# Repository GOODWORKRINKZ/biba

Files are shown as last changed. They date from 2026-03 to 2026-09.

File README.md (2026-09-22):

# BiBa




<p align="center">
   BiBa gradient ASCII logo
</p>

BiBa — это колесная робот-платформа с управлением по ExpressLRS/CRSF, телеметрией от Daly 6S BMS по BLE или USB-UART, двухканальными драйверами BTS7960 и звуковой индикацией через моторы. Платформа поддерживает три композиции железа — от чисто-Pi-варианта до связки одноплатник + STM32F103, поэтому репозиторий организован как hub: общие компоненты живут рядом, а сборки разводятся по подкаталогам.

## Архитектура

BiBa поддерживает три композиции железа. Где есть STM32 — именно он принимает CRSF и держит failsafe; одноплатник, если присутствует, работает как high-level brain поверх SPI-канала к STM32.

| Композиция | SBC (Raspberry Pi) | MCU add-on | Кто слушает CRSF | Compose / прошивка |
| --- | --- | --- | --- | --- |
| **A. Pi-only** (текущий продакшен) | да | нет | Pi (`/dev/ttyS0`) | [`docker/legacy-pi/docker-compose.yml`](docker/legacy-pi/docker-compose.yml) |
| **B. STM32-only** | нет | STM32F103 | STM32 | env `standalone` в [`firmware/`](firmware/) |
| **C. Pi + STM32** | да | STM32F103 | STM32 (Pi видит каналы через SPI-телеметрию) | env `companion` в [`firmware/`](firmware/) + ROS2-стек в `docker/ros2/` (в разработке) |
| **D. RP2040-only** (в разработке, ветка `rp2040-port`) | нет | RP2040 | RP2040 | env `rp2040_dc_bts7960_pwm_standalone` в [`firmware/`](firmware/) |

Канонический разбор композиций, их обязанности и failsafe-уровни — в [docs/system_architecture.md](docs/system_architecture.md). STM32-сторона детально описана в [docs/stm32_architecture.md](docs/stm32_architecture.md), будущий ROS2-стек композиции C — в [docs/ros2_stack.md](docs/ros2_stack.md). Общий design-doc и план редизайна — [docs/plans/2026-04-28-sbc-architecture-redesign-design.md](docs/plans/2026-04-28-sbc-architecture-redesign-design.md).

## Состав железа

- Raspberry Pi Zero 2W
- ELRS-приемник с подключением по UART/CRSF
- Daly BMS по BLE или с USB-UART адаптером
- 6S аккумулятор с телеметрией BMS
- Два драйвера BTS7960 для левого и правого моторов
- ADS1115 для current sense и телеметрии токов колёс (опционально)

## Распиновка

| Назначение | BCM | Физический пин |
| --- | --- | --- |
| ELRS TX | 14 | 8 |
| ELRS RX | 15 | 10 |
| I2C SDA (ADS1115, опционально) | 2 | 3 |
| I2C SCL (ADS1115, опционально) | 3 | 5 |
| Left BTS7960 RPWM | 12 | 32 |
| Left BTS7960 LPWM | 18 | 12 |
| Left BTS7960 REN | 23 | 16 |
| Left BTS7960 LEN | 24 | 18 |
| Right BTS7960 RPWM | 19 | 35 |
| Right BTS7960 LPWM | 13 | 33 |
| Right BTS7960 REN | 20 | 38 |
| Right BTS7960 LEN | 21 | 40 |
| GND драйвера | - | 14 |

Распиновка и таблица выше актуальны для композиции A (Pi-only). Для композиций B/C wiring между Pi, STM32 и силовой частью описан в [docs/wiring.md](docs/wiring.md) и [docs/stm32_architecture.md](docs/stm32_architecture.md).

Подробное описание подключения находится в [docs/wiring.md](docs/wiring.md).

Опциональная прошивка для STM32F103 ("Blue Pill") add-on, который умеет работать либо самостоятельно, либо SPI-slave-ом к Pi, живёт в [`firmware/`](firmware/). Архитектура описана в [docs/stm32_architecture.md](docs/stm32_architecture.md).

Текущий двухмоторный runtime на Pi Zero 2W должен быть запущен с `BTS7960_PWM_MODE=SOFTWARE`, потому что распиновка `12/18` и `19/13` делит общие hardware-PWM каналы. Это уже совпадает и с кодовым default в `config.py`, и с compose-default для развёрнутого робота.

## Структура репозитория

- `biba-controller/` — Python-контроллер для CRSF, моторов, моторного audio/voice runtime и телеметрии BMS (композиции A и C)
- `biba-controller/stm32_link/` — опциональный SPI-клиент к STM32F103 add-on (`STM32_LINK_ENABLED=1`, композиция C)
- `firmware/` — PlatformIO-проект прошивки (STM32F103C8T6 и RP2040): env'ы `standalone` для композиции B, `companion` для композиции C, `rp2040_dc_bts7960_pwm_standalone` для композиции D (ветка `rp2040-port`), `native_test` для host-side Unity-тестов
- `docker/` — каталог compose-стеков, разнесённых по композициям:
  - `docker/legacy-pi/` — текущий продакшен-стек композиции A
  - `docker/ros2/` — будущий ROS2-стек композиции C (в разработке)
  - `docker/base/` — общие базовые образы (в разработке)
- `lua/SCRIPTS/TELEMETRY/biba.lua` — экран телеметрии EdgeTX для оператора
- `.github/workflows/` — global builder workflows для Ruff, pytest, shellcheck и сборки arm64 Docker-образа в GHCR
- `scripts/setup/` — bringup-скрипты для Raspberry Pi (Docker, Compose, systemd-автозапуск)
- `scripts/biba_aliases.sh` — robot-side operational aliases, включая `bbupdate` для штатного обновления
- `scripts/diagnostics.sh` — диагностика хоста и контейнера
- `scripts/voice_prep.py` — офлайн-подготовка русскоязычных voice assets и явный promote в production voice каталог
- `voice-src/phrases.yml` — канонический набор русских фраз по событиям
- `voice-work/` — staging-каталог для сгенерированных кандидатов перед promote в production voice каталог
- `docs/deployment.md` — руководство по развёртыванию по композициям
- `docs/system_architecture.md` — канонический обзор всех трёх композиций
- `.agents/skills/` — вендорный каталог skills

## Quick-start по композициям

- **Композиция A (Pi-only).** Сегодняшний bringup-скрипт и compose-стек. Полный гайд: [docs/deployment.md](docs/deployment.md#композиция-a-pi-only).
- **Композиция B (STM32-only).** Без одноплатника. Сборка и заливка прошивки описаны в [firmware/README.md](firmware/README.md) и [docs/stm32_architecture.md](docs/stm32_architecture.md).
- **Композиция C (Pi + STM32).** В разработке. Проектная картина — в [design-doc](docs/plans/2026-04-28-sbc-architecture-redesign-design.md) и [docs/ros2_stack.md](docs/ros2_stack.md).

Дальше по тексту разделы про подготовку Pi, env-переменные, settings UI и motor trim относятся к композиции A.

## Подготовка Raspberry Pi (композиция A)

1. Включите UART на Raspberry Pi.
2. Освободите основной UART от Bluetooth, добавив в конфигурацию:

   ```ini
   enable_uart=1
   dtoverlay=disable-bt
   ```

3. Перезагрузите Raspberry Pi.
4. Настройте Daly BMS по BLE или подключите USB-UART адаптер, если используете UART-вариант.
5. Если используете ADS1115 для current sense, включите I2C и проверьте наличие `/dev/i2c-1`.

Вместо ручной установки Docker/Compose можно использовать bringup-скрипт:

```bash
curl -fsSL https://raw.githubusercontent.com/GOODWORKRINKZ/biba/main/scripts/setup/setup_node.sh | bash
```

Скрипт:

- ставит Docker и Docker Compose plugin
- ставит базовые системные утилиты
- клонирует или обновляет репозиторий в `~/biba`
- настраивает алиасы для управления стеком
- создает `systemd` unit для автозапуска `docker compose`

## Запуск (композиция A)

Компоновка стека лежит в [`docker/legacy-pi/docker-compose.yml`](docker/legacy-pi/docker-compose.yml). На роботе все стандартные действия выполняются через `bb*`-aliases из [`scripts/biba_aliases.sh`](scripts/biba_aliases.sh) (`bbupdate`, `bbstart`, `bbstop`, `bblogs`, `bbpull`).

Если удобно работать без алиасов — указывайте compose-файл явно:

```bash
docker compose -f docker/legacy-pi/docker-compose.yml pull
docker compose -f docker/legacy-pi/docker-compose.yml up -d
```

Локальная сборка:

```bash
docker compose -f docker/legacy-pi/docker-compose.yml build
docker compose -f docker/legacy-pi/docker-compose.yml up -d
```

Путь к compose-файлу можно переопределить переменной `BIBA_COMPOSE_FILE` для скриптов и алиасов.

Контейнер запускает `pigpiod`, слушает ELRS CRSF кадры на `/dev/ttyS0`, управляет моторами, опрашивает Daly BMS по BLE или на `/dev/ttyUSB0` и отправляет батарейную телеметрию обратно на передатчик.

Docker-образ собирается под `linux/arm64`, чтобы совпадать с Raspberry Pi Zero 2W. Для этого `pigpiod` собирается внутри образа из upstream `pigpio`, так как готовый пакет `pigpio` отсутствует в Debian bookworm arm64.

## Конфигурация и переменные окружения (композиция A)

Все env-переменные ниже применяются к compose-стеку композиции A в [`docker/legacy-pi/docker-compose.yml`](docker/legacy-pi/docker-compose.yml). Тип драйвера и распиновку можно переопределить через них:

- `MOTOR_DRIVER_TYPE=BTS7960|PWM_DIR`
- `BTS7960_PWM_MODE=HARDWARE|SOFTWARE` — для Pi Zero 2W с текущей двухмоторной проводкой нужен `SOFTWARE`
- `PWM_FREQUENCY_HZ=20000` — частота software PWM; актуально только при `BTS7960_PWM_MODE=SOFTWARE`
- `LEFT_MOTOR_RPWM=12`
- `LEFT_MOTOR_LPWM=18`
- `LEFT_MOTOR_REN=23`
- `LEFT_MOTOR_LEN=24`
- `LEFT_MOTOR_ENABLED=1` — отключить левый мотор целиком (для отладки)
- `RIGHT_MOTOR_RPWM=19`
- `RIGHT_MOTOR_LPWM=13`
- `RIGHT_MOTOR_REN=20`
- `RIGHT_MOTOR_LEN=21`
- `RIGHT_MOTOR_ENABLED=1` — отключить правый мотор целиком (для отладки)
- `MOTOR1_INVERTED=0|1`
- `MOTOR2_INVERTED=0|1`
- `CRSF_BAUD=420000` — скорость UART для CRSF-приёмника (менять не нужно для стандартного ELRS)
- `ARM_THRESHOLD=0.3` — нормализованный порог CH_ARM для арминга
- `THROTTLE_FILTER_MODE=NONE|KALMAN` — фильтрация газа до wheel-mix; `NONE` по умолчанию, `KALMAN` сглаживает выбросы канала
- `THROTTLE_KALMAN_PROCESS_NOISE=0.02` — насколько быстро фильтр принимает изменения реального setpoint
- `THROTTLE_KALMAN_MEASUREMENT_NOISE=0.5` — насколько сильно фильтр подавляет шум и ложные выбросы канала
- `CH_SPEED_MODE=5` — `CH6` на передатчике; трёхпозиционный селектор скоростного режима для controller-side scaling газа и руля
- `CH_DRIVE_MODE=6` — `CH7` на передатчике; селектор режимов движения: `manual` и `stabilized`
- `DRIVE_MODE_LOW_THRESHOLD=-0.3`, `DRIVE_MODE_HIGH_THRESHOLD=0.3` — пороги переключения drive mode аналогично speed mode
- `SPEED_MODE_LOW_THRESHOLD=-0.3` — нижний порог селектора в нормализованном диапазоне `-1..1`; ниже этого значения включается режим `1`
- `SPEED_MODE_HIGH_THRESHOLD=0.3` — верхний порог селектора в нормализованном диапазоне `-1..1`; выше этого значения включается режим `3`
- `SPEED_MODE_SLOW_SCALE=0.3333333333333333` — коэффициент для режима `1`
- `SPEED_MODE_MEDIUM_SCALE=0.6666666666666666` — коэффициент для режима `2`
- `SPEED_MODE_FAST_SCALE=1.0` — коэффициент для режима `3`
- `IMU_ENABLED=0|1` — включает autodetect IMU backend на I2C: BMI160/BMI166 или ST LSM6DS3-class
- `IMU_I2C_BUS=1`, `IMU_I2C_ADDRESS=104`, `IMU_EXPECTED_CHIP_ID=209` — параметры подключения IMU; на текущем роботе ST-модуль отвечает по `0x6A`, так что для него нужен `IMU_I2C_ADDRESS=106`
- `IMU_SAMPLE_RATE_HZ=100.0`, `IMU_STALE_TIMEOUT_S=0.2`, `IMU_GYRO_BIAS_CALIBRATION_S=1.0`, `IMU_GYRO_Z_SIGN=1.0` — частота чтения, timeout свежести, длительность bias-калибровки и знак yaw-оси
- `DRIVE_MODE_STEERING_DEADBAND=0.05`, `DRIVE_MODE_STEERING_LIMIT=1.0`, `DRIVE_MODE_YAW_RATE_MAX_DPS=90.0` — базовые ограничения assist-контура
- `DRIVE_MODE_YAW_RATE_KP/KI/KD` — tuning-параметры yaw-rate контура stabilized режима
- `DRIVE_MODE_YAW_RATE_DEADBAND_DPS`, `DRIVE_MODE_YAW_RATE_FILTER_HZ` — подавление мелкого gyro noise и сглаживание yaw-rate feedback
- `DRIVE_MODE_STABILIZATION_MIN_THROTTLE`, `DRIVE_MODE_NEUTRAL_STABILIZATION_STEERING_LIMIT`, `DRIVE_MODE_NEUTRAL_STABILIZATION_MAX_THROTTLE` — low-speed ограничения stabilized режима
- `PID_TUNING_SETTINGS_PATH=/data/pid-tuning.json` — persistent JSON с последними field-tuning значениями stabilized режима
- `LOW_CELL_VOLTAGE=3.5` — порог низкого напряжения ячейки для предупреждения `LOW` на Lua-экране
- `LOW_PACK_VOLTAGE=21.0` — порог низкого напряжения пакета (резервный, если ячейки не доступны)
- `BMS_BLE_ADDRESS=` — MAC-адрес BLE BMS (пустая строка = авто-поиск)
- `BMS_BLE_TIMEOUT_S=1.5` — таймаут BLE-операций
- `BMS_BLE_SERVICE_UUID`, `BMS_BLE_WRITE_UUID`, `BMS_BLE_NOTIFY_UUID` — UUID BLE-сервиса Daly (менять не нужно для стандартного Daly)
- `BMS_TELEMETRY_TRACE_ENABLED=0|1` — включает точные controller-side trace-логи на этапах consume/send для battery telemetry
- `BEACON_ENABLED=1` — включён по умолчанию; `0` отключает маяк совсем
- `BEACON_DELAY_S=300`
- `CH_BEACON=7` — `CH8` на передатчике; ручное включение маяка
- `CH_MUTE=9` — `CH10` на передатчике по умолчанию; канал мьюта обычных звуков, если нужен отдельный mute switch
- `CH_TRIM=8` — `CH9` на передатчике; в trim-mode используется как live-источник подстройки межколёсного баланса
- `MOTOR_TRIM_MAX_EFFECT=0.30` — максимальная коррекция, применяемая к одной стороне от полного хода `CH9`
- `MOTOR_TRIM_CONFIRM_HOLD_S=5.0` — сколько секунд держать trim-жест для входа и подтверждения
- `MOTOR_TRIM_SETTINGS_PATH=/data/motor-trim.json` — файл сохранённого trim на persistent Docker volume
- `ENABLE_RC_MELODIES=0|1` — включает выбор BLHeli-мелодий с передатчика
- `CH_MELODY=8` — канал выбора мелодии, если `ENABLE_RC_MELODIES=1`
- `STARTUP_MELODY=biba_signature` — стартовая BLHeli-мелодия при включённом melody-runtime
- `SOUND_MODE=SPECTRAL_VOICE|VOICE|SYNTH` — режим звуковой индикации: `SPECTRAL_VOICE` (по умолчанию) использует build-time spectral cache, `VOICE` — raw WAV, `SYNTH` — только BLHeli-мелодии без голоса
- `VOICE_SELECTION_MODE=ROUND_ROBIN|RANDOM` — порядок воспроизведения WAV при наличии нескольких вариантов на событие
- `MOTOR_TEST_API_ENABLED=1` — включён по умолчанию; `0` отключает встроенный HTTP settings UI контроллера
- `MOTOR_TEST_API_HOST=0.0.0.0` — bind host для settings UI
- `MOTOR_TEST_API_PORT=8765` — bind port для settings UI
- `RAMP_ACCEL_RATE=2.0` — скорость разгона мотора (единиц/сек, 0→100% за 0.5с)
- `RAMP_DECEL_RATE=2.0` — скорость отпускания/торможения (единиц/сек, 100%→0 за 0.5с)
- `RAMP_REVERSE_DECEL_RATE=0.5` — скорость подхода к нулю перед сменой направления; меньше значение = мягче переход в реверс
- `RAMP_ZERO_HOLD_S=0.15` — пауза на нуле (секунды) после торможения перед реверсом; даёт мотору физически остановиться и убирает «гавканье» BTS7960
- `MOTOR_DEADBAND=0.05` — мёртвая зона стика (меньше порога → мотор стоит)

Если нужно включить current sense через ADS1115, дополнительно задайте:

- `MOTOR_CURRENT_SENSE_ENABLED=1`
- `MOTOR_CURRENT_LIMITING_ENABLED=0|1` — включает software throttle back при превышении тока
- `MOTOR_CURRENT_SENSE_I2C_ADDRESS=72` (0x48 — стандартный адрес ADS1115)
- `MOTOR_CURRENT_SENSE_SAMPLE_RATE_HZ=32.0` — частота опроса ADS1115
- `MOTOR_CURRENT_SENSE_GAIN=1` — коэффициент усиления ADS1115 (1, 2, 4, 8, 16)
- `LEFT_MOTOR_CURRENT_SENSE_FORWARD_CHANNEL=2`, `LEFT_MOTOR_CURRENT_SENSE_REVERSE_CHANNEL=3`
- `RIGHT_MOTOR_CURRENT_SENSE_FORWARD_CHANNEL=0`, `RIGHT_MOTOR_CURRENT_SENSE_REVERSE_CHANNEL=1`
- `LEFT_MOTOR_CURRENT_SENSE_ZERO_OFFSET_V=0.0`, `RIGHT_MOTOR_CURRENT_SENSE_ZERO_OFFSET_V=0.0` — нулевые смещения для калибровки
- `LEFT_MOTOR_CURRENT_SENSE_AMPS_PER_VOLT=1.0`, `RIGHT_MOTOR_CURRENT_SENSE_AMPS_PER_VOLT=1.0` — коэффициент перевода напряжения в амперы
- `LEFT_MOTOR_MAX_CURRENT_A=18.0`, `RIGHT_MOTOR_MAX_CURRENT_A=18.0` — пороги ограничения тока
- `LEFT_MOTOR_MAX_POWER_W=180.0`, `RIGHT_MOTOR_MAX_POWER_W=180.0` — пороги ограничения мощности
- `MOTOR_LIMIT_FALLBACK_VOLTAGE=24.0` — напряжение пакета для расчёта мощности при отсутствии BMS данных

Для калибровочных заездов доступен отдельный trace-режим current sense:

- `MOTOR_CURRENT_TRACE_ENABLED=0|1` — включает JSONL-лог с motor activity, ADS1115 и BMS snapshot
- `MOTOR_CURRENT_TRACE_PATH=/data/current-trace.jsonl` — путь к trace-файлу на persistent volume
- `MOTOR_CURRENT_TRACE_POST_ROLL_S=2.0` — сколько секунд держать запись после окончания motor activity
- `MOTOR_CURRENT_TRACE_MIN_INTERVAL_S=0.0` — минимальный интервал между sample-записями; `0.0` означает без дополнительного rate limit

Этот trace нужен для офлайн-калибровки токов колёс против более медленного тока BMS и по умолчанию выключен.

Опциональные параметры STM32 SPI companion link (композиция C, выключен по умолчанию):

- `STM32_LINK_ENABLED=0|1` — включает SPI-клиент к STM32F103 add-on
- `STM32_LINK_SPI_BUS=0`, `STM32_LINK_SPI_DEVICE=0` — номер шины и устройства SPI
- `STM32_LINK_SPI_SPEED_HZ=8000000` — скорость SPI

Прочие:

- `LOG_LEVEL=INFO` — уровень логирования контроллера (`DEBUG`, `INFO`, `WARNING`, `ERROR`)

## Settings UI

Для инженерной проверки и полевого тюнинга на контроллере доступен встроенный HTTP settings UI:

- `http://<robot-ip>:8765/settings` — основной операторский экран
- `http://<robot-ip>:8765/motor-test` — legacy manual PWM page
- `http://<robot-ip>:8765/pid-tuning` — legacy PID-only page

Страница `/settings` собирает в одном месте:

- live platform status и revision state
- field tuning stabilized режима
- сохранённый motor trim с отображением live trim-mode значения
- ручной motor sound / PWM test

Backend surface для новой страницы:

- `GET /api/settings` — агрегированный snapshot platform, pid_tuning, motor_trim и motor_test
- `POST /api/settings/pid-tuning` — новые tuning-параметры stabilized режима
- `POST /api/settings/motor-trim` — сохранение нового trim пока платформа `disarmed`
- `POST /api/settings/motor-test` — короткий manual PWM test

PID tuning на `/settings` работает без рестарта контейнера и сразу сохраняется в `PID_TUNING_SETTINGS_PATH`. Обновления разрешены только пока платформа `disarmed`, а страница показывает `pending revision`, пока main loop не применит новый snapshot.

Motor trim на `/settings` показывает текущее сохранённое значение, queued revision state и live значение в trim-mode. Trim по-прежнему можно менять двумя путями:

- через операторскую страницу `/settings`
- через transmitter gesture в `disarm` с live источником на `CH9`

Legacy страницы `/motor-test` и `/pid-tuning` оставлены для совместимости и быстрых инженерных проверок.

Для текущего кода и текущего робота default уже `SOFTWARE`. Режим `HARDWARE` оставлен только для совместимых конфигураций, где PWM-линии не конфликтуют между собой.

Если после сборки одно из колёс едет в обратную сторону, достаточно выставить для него значение `1`.

Также поддерживается звуковая индикация через моторы:

- автоматический SOS после длительного failsafe
- ручное включение с тумблера передатчика через `CH_BEACON`
- режимы движения на `CH_DRIVE_MODE`: `manual`, `stabilized`
- общий мьют обычных звуков через `CH_MUTE`
- отключение маяка через `BEACON_ENABLED=0`

Отдельный hardware buzzer в текущей конфигурации не нужен: аудио, маяк и voice playback идут через моторный synth.

## Motor Trim

Для полевой подстройки прямолинейности робот поддерживает trim межколёсного баланса:

- при `disarm` держите первые четыре канала в максимуме 5 секунд, чтобы войти в trim-mode
- в trim-mode на Lua-экране появляется badge `t`
- пока trim-mode активен, контроллер берёт trim напрямую из `CH9`
- полный ход `CH9` используется целиком для точности, но на моторы применяется только до `MOTOR_TRIM_MAX_EFFECT` коррекции
- при повторном 5-секундном жесте в `disarm` текущее значение `CH9` сохраняется в `/data/motor-trim.json`
- после выхода из trim-mode используется уже сохранённое значение, а `CH9` снова игнорируется

То же сохранённое значение видно и редактируется на `http://<robot-ip>:8765/settings`.

Файл trim хранится на named Docker volume `biba-controller-data`, поэтому переживает перезапуск контейнера и обновление образа.

## Офлайн voice pipeline

Для голосовых ассетов используется офлайн-пайплайн, а не генерация речи на роботе.

Правила:

- канонические фразы в `voice-src/phrases.yml` должны быть на русском языке
- production runtime по умолчанию использует по одному утверждённому WAV на событие
- новые варианты сначала попадают в `voice-work/`, а не сразу в `biba-controller/voice/`
- при сборке controller image production WAV из `biba-controller/voice/` дополнительно преобразуются в derived spectral cache внутри image, чтобы робот не тратил секунды на FFT-предобработку при arm/disarm/connect voice events

Базовый цикл такой:

1. Обновить русские фразы в `voice-src/phrases.yml`.
2. Сгенерировать approved WAV-кандидаты в `voice-work/`.
3. Явно продвинуть их в production каталог командой `scripts/voice_prep.py promote-approved --manifest voice-src/phrases.yml --base-dir voice-work --repo-root .`.
4. Закоммитить обновлённые WAV в ветку и доставить их на робота через штатный robot-side update workflow `bbupdate`.

Так production voice assets обновляются предсказуемо и без отдельного audition runtime path.

Сами spectral cache artifacts в git не хранятся. Они пересобираются внутри Docker image и в runtime используются автоматически для production voice путей, а для временных или нестандартных WAV контроллер по-прежнему умеет падать обратно на live-анализ.

## CI и образы

GitHub Actions выполняет:

- `ruff check biba-controller/ tests/`
- `pytest`
- сборку arm64 Docker-образа через Buildx на стороне GitHub Actions
- push глобального образа в GHCR

Workflow'ы организованы по схеме `G-*`:

- `G-Build-Controller-Image.yml` — линт, тесты, сборка и push образа контроллера
- `G-Build-All.yml` — верхнеуровневый запуск полной сборки проекта

Базовая модель деплоя композиции A:

```bash
docker compose -f docker/legacy-pi/docker-compose.yml pull
docker compose -f docker/legacy-pi/docker-compose.yml up -d
```

Либо на роботе через alias `bbupdate` (`scripts/biba_aliases.sh`).

Raspberry Pi не обязан собирать образ локально, он просто забирает готовый arm64-образ из GHCR.

Полное руководство по развёртыванию: [docs/deployment.md](docs/deployment.md)

## Экран телеметрии

Скопируйте `lua/SCRIPTS/TELEMETRY/biba.lua` на SD-карту передатчика в каталог `SCRIPTS/TELEMETRY/`, затем добавьте скрипт как экран телеметрии в EdgeTX/OpenTX.

Текущая версия экрана показывает:

- общее напряжение батареи
- ток в mA
- SOC в процентах
- link quality `RQly`
- 6 ячеек батареи
- `min/max/delta` по ячейкам
- CPU и RAM контроллера
- ток левого и правого моторов
- локальные бейджи `a/b/mode` и speed badge для arm, beacon, drive mode и speed mode
- бейдж `t`, когда на роботе активен trim-mode
- бейдж зарядки, когда батарея находится в состоянии `CHG`
- мигающее предупреждение `LOW`, если минимальная ячейка уходит ниже порога
- wheel animation по throttle/steering с передатчика
- VCP serial logging для захвата telemetry screen данных

Скрипт пытается читать реальные cell sensors (`Cels`), а если передатчик их не отдает, использует fallback-оценку от общего напряжения пакета. Для robot-side status он использует существующие telemetry bits из battery capacity field, а `a/m/b` берёт локально с передатчика.

Для токов колёс semantic contract теперь считается BIBA-специфичным: controller нормализует левый и правый wheel current в канонические значения, а Lua-экран читает уже BIBA-layer helpers. Текущий CRSF carrier mapping через GPS-поля остаётся лишь transport-совместимостью и не должен использоваться как UI-level контракт.

## Каталог skills

В репозитории присутствует вендорный каталог `.agents/skills/`, чтобы локально использовать тот же набор skills, что и в другом рабочем окружении. На первом проходе импорт выполнен без адаптации содержимого.

## Дорожная карта

**Текущий milestone: RP2040 Port** — портирование управляющего runtime на RP2040 как standalone embedded target (ветка `rp2040-port`).

| Фаза | Цель | Статус |
| --- | --- | --- |
| **Phase 1: Core Drive** | CRSF + BTS7960 PWM + Arming/Failsafe + SpeedRamp | В работе (01–04 выполнены, финальная сборка) |
| **Phase 2: Stabilization & Sensing** | IMU heading-hold + current sense + trim persistence | Не начата |
| **Phase 3: Field Ready** | Тепловая защита ESC + матрица вариантов + полевой тест | Не начата |

Полевые испытания проведены 09.05.2026 (двор). Основная проблема — тепловой режим BTS7960 при длительной езде; решается аппаратно (крепёж плат на металлическую пластину).

Долгосрочные направления (за пределами RP2040 Port):

- BMS интеграция и голос на RP2040 (отложено — недостаточно RAM)
- ROS2-ноды для Pi Zero 2W (отдельный milestone)
- Follow-me режим, автономная навигация (после field-ready RP2040)

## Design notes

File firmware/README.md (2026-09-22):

# Прошивка BiBa для RP2040

Проект PlatformIO для плат класса RP2040 (Raspberry Pi Pico-class), на
которых работает BiBa либо в standalone-режиме, либо в роли companion
при Raspberry Pi.

Проект использует **раскладку таргетов в стиле Betaflight/ELRS**: каждая
поддерживаемая аппаратная конфигурация — это отдельная директория в
[`targets/`](targets), а матрица сборки строится как `<target> × <режим>`.
Полное руководство «как добавить новый target» см. в
[`targets/README.md`](targets/README.md).

STM32-таргеты (Blue Pill / BIBA_F103_REV_A) удалены из проекта — они
больше не собираются и не поддерживаются.

## Матрица сборки

Имя env собирается как `<target_lowercase>_<mode>`. Поддерживается четыре режима:

| Режим | Что собирается |
| --- | --- |
| `standalone`  | RP2040 сам управляет CRSF + мотор-драйвером + лимитером + heading-hold. |
| `companion` | RP2040 работает как slave, уставки приходят с SBC. |
| `combined` | Оба режима в одном бинарнике, выбор при старте по пину MODE_SEL. |
| `native_test` | Хостовые юнит-тесты переносимых модулей (без таргета). |

Текущие таргеты — см. таблицу в [`targets/README.md`](targets/README.md#поддерживаемые-таргеты).

## Сборка и прошивка

```bash
cd firmware

# дефолтный env (RP2040_DC_BTS7960_PWM standalone)
pio run

# явный target × режим
pio run -e rp2040_dc_bts7960_pwm_standalone
pio run -e rp2040_dc_bts7960_pwm_companion

# BLDC/CAN вариант
pio run -e rp2040_bldc_odrive_can_standalone
pio run -e rp2040_bldc_odrive_can_companion
pio run -e rp2040_bldc_odrive_can_combined

# BLDC на ODrive по UART (ASCII)
pio run -e rp2040_bldc_odrive_uart_standalone
pio run -e rp2040_bldc_odrive_uart_companion
pio run -e rp2040_bldc_odrive_uart_combined

# BLDC на VESC (Flipsky dual FSESC) по CAN
pio run -e rp2040_bldc_vesc_can_standalone
pio run -e rp2040_bldc_vesc_can_companion
pio run -e rp2040_bldc_vesc_can_combined

# мост HotRC PWM → CRSF (отдельная Pico вместо ELRS-приёмника)
pio run -e rp2040_bridge_pwm2crsf

# прошивка через picotool
pio run -e rp2040_dc_bts7960_pwm_standalone -t upload

# хостовые юнит-тесты (не зависят от таргета)
pio test -e native_test
```

CI (`.github/workflows/G-Build-Firmware-Native-Tests.yml`) прогоняет
только `pio test -e native_test`; сборка под конкретный таргет в CI не
производится и делается локально.

## Раскладка проекта

```
firmware/
├── platformio.ini             # матрица env'ов target × режим
├── include/                   # тонкие шимы -> targets/<TARGET>/target*.h
├── src/
│   ├── main_rp2040.cpp        # точка входа Arduino (setup/loop), вызывает диспетчер режимов
│   ├── app/                   # переносимая логика контроля (PID, лимитер, телеметрия)
│   ├── drivers/               # мотор-драйверы, ADC, CRSF, IMU, MCP2515/CAN, ODrive
│   ├── hal/                   # обёртка над RP2040/Pico SDK (тактирование, DMA, периферия)
│   ├── modes/                 # standalone / companion / диспетчер
│   └── proto/                 # общий с SBC формат кадров
├── targets/
│   ├── README.md              # как добавить новый таргет
│   ├── RP2040_DC_BTS7960_PWM/    # {target.h, target_config.h, target.md}
│   ├── RP2040_BLDC_ODRIVE_CAN/   # BLDC: ODrive по CAN (MCP2515)
│   ├── RP2040_BLDC_ODRIVE_UART/  # BLDC: ODrive по UART1 ASCII
│   ├── RP2040_BLDC_VESC_CAN/     # BLDC: Flipsky dual FSESC по CAN
│   └── RP2040_BRIDGE_PWM2CRSF/   # мост HotRC 6×PWM → CRSF (src/pwm2crsf/)
└── test/                      # хостовые тесты на Unity для переносимых модулей
```

## Разделение переносимого и таргет-специфичного кода

Всё в `src/app/` (кроме `telemetry.c`), `src/drivers/crsf.*` и
`src/proto/` — это строго переносимый C без include'ов HAL и без
зависимости от `target.h`. Эти модули покрыты юнит-тестами на хосте
через `pio test -e native_test`. Остальное (всё, что лезет в железо
или включает Pico SDK / Arduino-заголовки) исключается из native env
через `build_src_filter` в `platformio.ini`.

Аппаратный код подключает `biba_board.h` (шим распиновки) и
`biba_config.h` (политика + переопределения таргета); оба заголовка
резолвят `target.h` / `target_config.h` через путь `-I targets/<TARGET>`,
который PlatformIO добавляет в каждом env.

## Протокол SPI

Описан в [`docs/stm32_architecture.md`](../docs/stm32_architecture.md).
Тот же формат реализован на стороне SBC в
`biba-controller/stm32_link/protocol.py`; константа версии в
`include/biba_version.h` обязана совпадать с `PROTOCOL_VERSION` там.

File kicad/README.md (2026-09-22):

# KiCad workspace — BiBa

Здесь живут все KiCad-проекты (схемы и платы) проекта BiBa.

## Структура

```
kicad/
├── README.md                  ← этот файл
├── common/                    ← общие библиотеки (не дублировать по вариантам)
│   ├── symbols/               ← .kicad_sym (общие символы)
│   ├── footprints/            ← .pretty / .kicad_mod (общие футпринты)
│   └── 3dmodels/              ← .step / .wrl
└── variants/                  ← варианты схем
    └── brushed-bts7960/       ← вариант №1: коллекторные моторы + BTS7960
```

## Как устроен вариант

Каждый вариант = отдельный KiCad-проект в `variants/<name>/`:

- `<name>.kicad_pro` — проект
- `<name>.kicad_sch` — схема
- `<name>.kicad_pcb` — плата (если есть)
- `README.md` — план варианта: таргет, распиновка, BOM, статус

Источник истины по пинам — `firmware/targets/*/target.h` и `target.md`.
Схема обязана им соответствовать.

## Соглашения

- Распиновка в схеме = распиновка в `target.h`.
- Общие библиотеки кладём только в `common/`.
- Новый вариант: копируем структуру существующего и пишем `README.md` с планом.
- Документация по вариантам — на русском.

## Импорт из EasyEDA

Исходники EasyEDA лежат в `variants/<name>/easyeda/`, конвертеры — в `scripts/`:

| Скрипт | Что делает |
|---|---|
| `easyeda_netlist.py` | разбирает исходник в `netlist.json` / `components.tsv` |
| `easyeda_sch2kicad.py` | схема EasyEDA → `.kicad_sch` (графика символов 1:1) |
| `gen_pcb.py` | плата EasyEDA → `.kicad_pcb` + `common/footprints/biba.pretty/` |

Плату импортирует штатный конвертер KiCad (`kicad-cli pcb import`), `gen_pcb.py`
поверх него приводит результат к виду репозитория: имена слоёв, библиотека
футпринтов, правила DRC из исходника, перезаливка полигонов. Ему нужен Python
из состава KiCad — ищется сам, при нестандартной установке задайте `KICAD_HOME`.

Имена футпринтов в схеме и на плате должны совпадать, поэтому оба генератора
берут их из общей функции `easyeda_netlist.footprint_name()`.

`gen_schematic.py` — ранний генератор схемы «на глобальных метках», оставлен
для истории; актуальный — `easyeda_sch2kicad.py`.

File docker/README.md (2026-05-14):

# docker/

Этот каталог содержит compose-стеки и базовые образы для всех аппаратных композиций BiBa. См. [docs/system_architecture.md](../docs/system_architecture.md).

| Подкаталог | Композиция | Описание |
| --- | --- | --- |
| [`legacy-pi/`](legacy-pi/) | A. Pi-only | Текущий рабочий compose с `biba-controller` Python-runtime |
| [`ros2/`](ros2/) | C. Pi + STM32 | ROS2-стек (в разработке) |
| [`base/`](base/) | общий | Базовые Docker-образы (в разработке) |

Композиция B (STM32-only) не содержит SBC и compose-стека не имеет — её прошивка живёт в [`firmware/`](../firmware/).

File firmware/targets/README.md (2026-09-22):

# Таргеты прошивки

Прошивка BiBa организована так же, как у Betaflight и ELRS:
переносимый код лежит в `src/`, а каждая поддерживаемая **аппаратная
конфигурация** (распиновка, масштаб токового сенсора, наличие
периферии) получает собственную директорию `targets/<TARGET>/`.

Таргет полностью описывается тремя файлами:

```
targets/<TARGET>/
├── target.h            # распиновка + флаги BIBA_TARGET_HAS_*
├── target_config.h     # калибровки и лимиты под конкретную плату
└── target.md           # документация: чем этот таргет отличается от других
```

Переносимый код в `src/` подключает только `biba_board.h` и
`biba_config.h` — это тонкие шимы, которые включают `target.h` /
`target_config.h` через путь `-I targets/<TARGET>`, добавляемый
PlatformIO в каждом env. Никаких лесенок `#ifdef TARGET == …` в `src/`
нет.

## Стандарт имён

Имя таргета — это четыре слота через подчёркивание:

```
<MCU>_<MOTOR>_<DRIVER>_<LINK>
 │      │       │        └── как МК разговаривает с драйвером: PWM / CAN / UART
 │      │       └─────────── чем крутим: BTS7960 / ODRIVE / VESC
 │      └─────────────────── тип мотора: DC (щёточный) / BLDC
 └────────────────────────── микроконтроллер: RP2040
```

Читается слева направо как «RP2040, бесколлекторные моторы, драйверы
VESC, связь по CAN» → `RP2040_BLDC_VESC_CAN`.

Почему слот линка отдельный, а не флаг сборки: **линк меняет
распиновку**. У `RP2040_BLDC_ODRIVE_CAN` занят SPI0 под MCP2515, у
`RP2040_BLDC_ODRIVE_UART` эти пины свободны, зато занят UART1. Это
разное железо, а таргет в этом проекте описывает именно железо.
Обоснование — `docs/adr/0002-target-naming-and-vesc.md`.

Плата, которая **не крутит моторы**, слотов MOTOR/DRIVER не имеет и
называется `<MCU>_BRIDGE_<FUNCTION>` — сейчас это только
`RP2040_BRIDGE_PWM2CRSF`.

Имя env — то же самое в нижнем регистре плюс режим:
`<target_lowercase>_<mode>`.

## Поддерживаемые таргеты

| Target | Мотор | Драйвер | Линк | Плата / особенности |
| --- | ----- | --- | ---- | --- |
| `RP2040_DC_BTS7960_PWM` | щёточный DC | BTS7960 ×2 | прямой PWM | Pico + BTS7960, SBC по UART1. Таргет по умолчанию (`default_envs`). |
| `RP2040_BLDC_ODRIVE_CAN`  | BLDC  | ODrive Pro/S1/Micro ×2 | CAN (MCP2515 на SPI0 GP16–19, INT=GP15) | 250 кбит/с, CANSimple, 11-bit ID. BTS7960 и native ADC отключены. Архитектура — `docs/adr/0001-pico-bldc-target.md`. |
| `RP2040_BLDC_ODRIVE_UART` | BLDC  | ODrive Pro/S1/Micro ×2 | UART1 ASCII (GP4/GP5) | Без MCP2515 (`BIBA_TARGET_HAS_MCP2515 = 0`). Сейчас предпочтительный production-линк: CANSimple в прошивке ODrive 0.5.6 залипает на холостом ходу. |
| `RP2040_BLDC_VESC_CAN` | BLDC  | Flipsky dual FSESC (спаренный VESC) | CAN (тот же MCP2515-мост) | 500 кбит/с, 29-bit extended ID, big-endian, accept-all фильтры. Драйвер — `src/drivers/vesc_can.c`. |
| `RP2040_BRIDGE_PWM2CRSF`  | — | — | — | Не контроллер бибы: отдельная Pico-мост, 6×PWM с приёмника HotRC → CRSF, ставится вместо ELRS-приёмника. Один env, без режимов. |

STM32-таргеты (`BLUEPILL_F103C8`, `BLUEPILL_F103C8_CLONE`,
`BIBA_F103_REV_A`) удалены — проект не собирает прошивку под STM32.

## Матрица сборки

Каждый таргет привода комбинируется с режимами прошивки
(`standalone` / `companion` / `combined`):

```bash
# щёточные DC на BTS7960
pio run -e rp2040_dc_bts7960_pwm_standalone
pio run -e rp2040_dc_bts7960_pwm_companion

# BLDC на ODrive по CAN
pio run -e rp2040_bldc_odrive_can_standalone
pio run -e rp2040_bldc_odrive_can_companion
pio run -e rp2040_bldc_odrive_can_combined

# BLDC на ODrive по UART (ASCII)
pio run -e rp2040_bldc_odrive_uart_standalone
pio run -e rp2040_bldc_odrive_uart_companion
pio run -e rp2040_bldc_odrive_uart_combined

# BLDC на VESC по CAN
pio run -e rp2040_bldc_vesc_can_standalone
pio run -e rp2040_bldc_vesc_can_companion
pio run -e rp2040_bldc_vesc_can_combined

# мост HotRC PWM → CRSF (отдельная плата, режимов нет)
pio run -e rp2040_bridge_pwm2crsf

# переносимые хостовые тесты (без таргета)
pio test -e native_test
```

Плюс два bring-up PoC-env'а, не входящих в матрицу режимов:

```bash
pio run -e rp2040_bldc_odrive_can_loopback_poc   # SPI↔MCP2515 self-test
pio run -e rp2040_dc_bts7960_pwm_is_poc          # IS-pin / RPM PoC
```

CI-workflow `.github/workflows/G-Build-Firmware-Native-Tests.yml`
запускает только `pio test -e native_test`; сборка под конкретный
таргет прошивки в CI не производится и делается локально.

## Как добавить новый таргет

1. **Выбери имя по стандарту** `<MCU>_<MOTOR>_<DRIVER>_<LINK>`
   (см. выше). Если отличается только линк — это всё равно новый
   таргет, а не флаг.

2. **Скопируй ближайший по распиновке таргет.** Возьми тот, чья
   распиновка ближе всего к твоей плате, и скопируй директорию:

   ```bash
   cp -r firmware/targets/RP2040_DC_BTS7960_PWM firmware/targets/<YOUR_TARGET>
   ```

3. **Отредактируй `target.h`.** Поставь свой `BIBA_TARGET_NAME`,
   переключи флаги `BIBA_TARGET_HAS_*` под своё железо (например,
   отключи IMU, если на плате нет I²C-шины) и поправь все макросы
   `BIBA_PIN_*_PORT/PIN`. Не убирай комментарии-секции — код в
   `src/hal/biba_hal.c` ищет именно эти имена макросов.

4. **Отредактируй `target_config.h`.** Переопредели калибровочные
   константы (масштаб тока, делитель батареи, лимит тока на сторону).
   Переопределяй только то, что реально отличается — `include/biba_config.h`
   подставляет дефолты через `#ifndef`-гарды.

5. **Зарегистрируй таргет в `platformio.ini`.** Добавь одну секцию
   `[target_*]`, при необходимости свой `[*_src_filter]`, и по одному
   блоку `[env:*_<mode>]` на каждый режим прошивки. Пример для нового
   `RP2040_DC_MYDRIVER_PWM`:

   ```ini
   [target_rp2040_dc_mydriver_pwm]
   board = rpipico
   target_include = targets/RP2040_DC_MYDRIVER_PWM
   build_flags = -DBIBA_TARGET_RP2040_DC_MYDRIVER_PWM=1

   [env:rp2040_dc_mydriver_pwm_standalone]
   platform = https://github.com/maxgerhardt/platform-raspberrypi.git
   framework = arduino
   board = ${target_rp2040_dc_mydriver_pwm.board}
   upload_protocol = picotool
   debug_tool = cmsis-dap
   build_src_filter = ${rp2040_dc_src_filter.build_src_filter}
   build_flags =
       -Iinclude
       -Isrc
       -Isrc/proto
       -I${target_rp2040_dc_mydriver_pwm.target_include}
       ${target_rp2040_dc_mydriver_pwm.build_flags}
       ${mode_standalone.build_flags}
       -Wl,-u,_printf_float
   ```

6. **Добавь строку в таблицу выше.** CI собирает только
   `pio test -e native_test` (см.
   `.github/workflows/G-Build-Firmware-Native-Tests.yml`); сборка под
   конкретный таргет делается локально командой `pio run -e ...`.

7. **Опиши плату** в `target.md` — как минимум разницу по пинам с
   каким-нибудь существующим таргетом. Это держит знание «чем особенна
   эта плата?» рядом с кодом, который её реализует.

8. **Обнови `docs/variants.md`** — матрица вариантов железа.

## Как добавить новый BLDC-драйвер

Все BLDC-бэкенды реализуют один контракт — `src/drivers/bldc.h`
(`biba_bldc_init` / `_set_enabled` / `_drive` / `_tick_50hz` / …).
Код режимов в `src/modes/*.c` вызывает только его и не знает, ODrive
там или VESC.

1. Напиши `src/drivers/<driver>_<link>.c`, реализующий все функции
   из `bldc.h`. В начале файла поставь `#error`-якорь на свой флаг
   бэкенда, чтобы файл нельзя было случайно собрать не туда
   (см. шапку `vesc_can.c`).
2. Заведи флаг `BIBA_TARGET_BLDC_BACKEND_<DRIVER>` в `target.h`
   нового таргета; ровно один из BACKEND-флагов должен быть `1`.
3. Заведи в `platformio.ini` свой `[*_src_filter]`: включи свой TU
   и **исключи остальные бэкенды** — иначе линкер получит несколько
   определений `biba_bldc_drive`.
4. Если линк — CAN, переиспользуй `drivers/mcp2515.c` +
   `drivers/can_queue.c`. Драйвер MCP2515 умеет 11- и 29-битные ID,
   100/250/500 кбит/с (`BIBA_CAN_BITRATE_BPS`) и режим accept-all
   (`BIBA_MCP2515_ACCEPT_ALL`).

## Контракт переносимого кода

Перечисленные ниже макросы заголовка считаются **ABI таргета**.
Добавление, удаление или переименование любого из них — ломающее
изменение; имена должны полностью совпадать с тем, как они написаны в
`RP2040_DC_BTS7960_PWM/target.h`:

- `BIBA_TARGET_NAME`
- `BIBA_TARGET_HAS_BTS7960_2CH` — `1`, если две BTS7960-линии +
  токовые шунты присутствуют и режим `biba_bts7960_*` собирается; `0`,
  если используется альтернативный motor backend (BLDC-таргеты).
- `BIBA_TARGET_HAS_BLDC_2CH` — `1`, если таргет компонуется с
  `biba_bldc_*` API (`src/drivers/bldc.h`). Только один из
  `BTS7960_2CH` / `BLDC_2CH` может быть `1` одновременно.
  Введён ADR-0001.
- `BIBA_TARGET_BLDC_BACKEND_ODRIVE` / `BIBA_TARGET_BLDC_BACKEND_VESC` —
  какой бэкенд реализует `bldc.h` на этом таргете. Ровно один может
  быть `1`; обязательны при `BIBA_TARGET_HAS_BLDC_2CH == 1`.
  Введены ADR-0002.
- `BIBA_TARGET_HAS_MCP2515` — `1`, если на плате есть
  аппаратный мост SPI↔CAN (MCP2515). По нему `hal/biba_hal_motor_bldc.c`
  условно разводит INT-пин на ISR. Введён ADR-0001.
- `BIBA_TARGET_HAS_CRSF`
- `BIBA_TARGET_HAS_IMU`
- `BIBA_TARGET_HAS_SPI_SLAVE`
- `BIBA_TARGET_HAS_PER_CHANNEL_TIMER_PWM` — `1`, если каждая из четырёх
  PWM-линий мотора висит на своём аппаратном таймере (это включает
  motor-audio); `0`, если все четыре делят один таймер
- `BIBA_PIN_{LEFT,RIGHT}_{RPWM,LPWM,REN,LEN}_{PORT,PIN}`
- При `BIBA_TARGET_HAS_PER_CHANNEL_TIMER_PWM == 1` дополнительно:
  `BIBA_PWM_{LEFT,RIGHT}_{RPWM,LPWM}_{TIM,CHANNEL,CLK_ENABLE,AF_REMAP}`
- `BIBA_ADC_CHAN_*` и `BIBA_ADC_SCAN_LEN`
- `BIBA_PIN_{CRSF_TX,CRSF_RX,SPI_*,DATA_READY,MODE_SEL,I2C_*,IMU_INT1,STATUS_LED}_{PORT,PIN}`
- `BIBA_STATUS_LED_ACTIVE_LOW`

Если плата принципиально не может предоставить какой-то из пинов
(нет SPI-slave, нет IMU и т. п.) — выставь соответствующий
`BIBA_TARGET_HAS_*` в 0 и не определяй макросы пинов; HAL уже
загораживает соответствующий init-код этим флагом.

Пин-макросы SPI0 (`BIBA_PIN_SPI0_MISO_GPIO`, `BIBA_PIN_SPI0_SCK_GPIO`,
`BIBA_PIN_SPI0_MOSI_GPIO`, `BIBA_PIN_SPI0_CS_GPIO`) и
`BIBA_PIN_MCP2515_INT_GPIO` обязательны только при
`BIBA_TARGET_HAS_MCP2515 == 1`; на остальных таргетах они не
определяются.

Адресация BLDC-узлов — `BIBA_BLDC_LEFT_NODE_ID` /
`BIBA_BLDC_RIGHT_NODE_ID` в `target_config.h`, одинаково для всех
бэкендов (у ODrive это node_id CANSimple, у VESC — controller id).

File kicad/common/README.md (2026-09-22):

# Общие библиотеки KiCad

- `symbols/` — общие символы (`.kicad_sym`): разъёмы, модули, специфичные для BiBa.
  `biba.kicad_sym` генерируется `scripts/easyeda_sch2kicad.py` — руками не правим.
- `footprints/` — общие футпринты (`.kicad_mod`, папки `.pretty`).
  `biba.pretty/` генерируется `scripts/gen_pcb.py` с платы — руками не правим.
- `3dmodels/` — 3D-модели (`.step` / `.wrl`) для 3D-вида плат. Пока пусто.

Символы/футпринты, специфичные для одного варианта, хранятся в каталоге
этого варианта, а не здесь.

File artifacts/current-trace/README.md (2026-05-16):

# Current Trace Artifacts

This directory stores current-trace evidence used by Phase 3 field validation.

## Filename format

Use one run file per validation session:

- `current-trace-YYYYMMDD-HHMMSS-<run_id>.jsonl`

Example:

- `current-trace-20260516-173000-phase3-run01.jsonl`

## Runtime controls

Current trace in controller runtime is controlled by:

- `MOTOR_CURRENT_TRACE_ENABLED=1`
- `MOTOR_CURRENT_TRACE_PATH=/data/current-trace.jsonl`

These values are read by `biba-controller/main.py` and written as JSONL records.

## Required metadata keys

Each run must include metadata (in a companion `.meta.json` file or header record):

- `run_id`
- `timestamp_start`
- `timestamp_end`
- `operator`
- `firmware_target`
- `git_revision`
- `battery_pack_id`
- `ambient_temp_c`
- `protocol_version`
- `result`

## Validation mapping

This evidence supports:

- thermal behavior review during the 30-minute protocol
- pass/fail decisions in `docs/field-validation.md`
- requirement traceability in Phase 3 UAT

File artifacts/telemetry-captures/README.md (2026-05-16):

# Telemetry Capture Artifacts

This directory stores serial/VCP telemetry captures for field validation runs.

## Capture command

Use the repository capture tool:

```bash
python3 scripts/vcp_capture.py --help
```

Typical run:

```bash
python3 scripts/vcp_capture.py --device /dev/ttyACM0 --baud 115200
```

Default output path:

- `artifacts/telemetry-captures/vcp-YYYYMMDD-HHMMSS.log`

## Filename format

Prefer explicit run IDs when possible:

- `vcp-YYYYMMDD-HHMMSS-<run_id>.log`

## Required metadata keys

Each capture set must include metadata (sidecar file or UAT record):

- `run_id`
- `capture_file`
- `timestamp_start`
- `timestamp_end`
- `operator`
- `firmware_target`
- `git_revision`
- `battery_pack_id`
- `result`

## Validation mapping

Telemetry captures support:

- event timeline reconstruction for 30-minute protocol
- correlation with current trace artifacts
- evidence completeness checks in `docs/field-validation.md`

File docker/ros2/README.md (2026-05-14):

# ROS2-стек композиции C (Pi + STM32)

Minimal-профиль docker-compose, поднимаемый на Pi Zero 2W (или старше) поверх legacy `biba-controller` или вместо него.

## Сервисы

| Сервис | Команда | Что делает |
| --- | --- | --- |
| `zenoh-router` | `ros2 run rmw_zenoh_cpp rmw_zenohd` | Bootstrap discovery для всех ROS2-нод этого Pi |
| `biba-control` | `ros2 launch biba_bringup control.launch.py` | `controller_manager` + `diff_drive_controller` поверх `biba_hardware_stm32` SystemInterface; единственный владелец `/dev/spidev0.0`. Также поднимает `robot_state_publisher`. |
| `twist-mux` | `ros2 launch biba_bringup twist_mux.launch.py` | Арбитраж `cmd_vel_*` источников → `/cmd_vel` (см. [config](../../ros2_ws/src/biba_bringup/config/twist_mux.yaml)) |

Python-узел `biba_stm32_bridge` исключён из композиции C: SPI теперь принадлежит C++-плагину `biba_hardware_stm32::BibaStm32SystemHardware`, и `diff_drive_controller` пишет в него напрямую через `velocity` command interface.

Все сервисы используют один и тот же образ `ghcr.io/goodworkrinkz/biba/biba-ros2:<tag>` ([Dockerfile](Dockerfile)), который собирается поверх `biba-ros2-control` ([../base/](../base/)) и содержит сборку `ros2_ws/` через `colcon`.

## Quick start

```bash
cd docker/ros2
cp .env.example .env             # подкрутить теги и параметры

# Вариант A: pull готового образа из GHCR (после первого CI-прогона G-Build-ROS2-Stack)
docker compose pull

# Вариант B: собрать локально (медленно на Pi Zero 2W; обычно делается на dev-машине через buildx + arm64)
docker compose build

docker compose up -d
docker compose logs -f biba-control
```

## Топики и сервисы

- `/cmd_vel` (sub, `geometry_msgs/Twist`) — вход `diff_drive_controller` (выход `twist-mux`)
- `cmd_vel_teleop`, `cmd_vel_uwb`, `cmd_vel_nav` — приоритезированные входы `twist-mux` (см. [biba_bringup/config/twist_mux.yaml](../../ros2_ws/src/biba_bringup/config/twist_mux.yaml))
- `/biba/estop` (sub, `std_msgs/Bool`) — `twist-mux` lock; `true` блокирует все twist-входы
- `/odom` (pub, `nav_msgs/Odometry`) — open-loop одометрия от `diff_drive_controller`
- `/joint_states` (pub, `sensor_msgs/JointState`) — состояние колёсных joint'ов
- `/tf` — `odom → base_link → wheels/imu/stm32` (RSP + diff_drive)
- `/controller_manager/*` (srv) — стандартные services управления контроллерами

## Переменные окружения

См. [`.env.example`](.env.example). Ключевые:

- `BIBA_ROS2_IMAGE_TAG` — тег сервисного образа (`latest` / `dev` / `<sha>`)
- `ROS_DOMAIN_ID`, `ROS_AUTOMATIC_DISCOVERY_RANGE` — настройка Zenoh

Геометрия дифф-привода (`wheel_separation`, `wheel_radius`, `max_wheel_speed`) теперь живёт в [`biba_description/urdf/biba.urdf.xacro`](../../ros2_ws/src/biba_description/urdf/biba.urdf.xacro) и [`biba_bringup/config/diff_drive_controller.yaml`](../../ros2_ws/src/biba_bringup/config/diff_drive_controller.yaml). Калибровать там, не через env.

## Совместимость с legacy-стеком

Этот compose НЕ запускает `biba-controller` legacy (`docker/legacy-pi/`). На текущем этапе они взаимоисключающие — оба претендуют на SPI/GPIO. Композиция C, при которой один Pi одновременно гоняет legacy-RC и ROS2, описана в [`docs/system_architecture.md`](../../docs/system_architecture.md) и реализуется отдельным эпиком (split SPI владельца).

Дизайн: [`docs/plans/2026-04-28-sbc-architecture-redesign-design.md`](../../docs/plans/2026-04-28-sbc-architecture-redesign-design.md).

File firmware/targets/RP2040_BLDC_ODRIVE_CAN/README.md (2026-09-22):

# Таргет `RP2040_BLDC_ODRIVE_CAN` — BLDC/ODrive через CAN

Этот документ — пошаговая инструкция по запуску таргета «с нуля»: что
купить, как спаять, как собрать, как прошить, как проверить, что всё
работает. Архитектурные обоснования выбора железа и протокола лежат в
`docs/adr/0001-pico-bldc-target.md`, фундаментальное сравнение пинов с
соседним таргетом — в [`target.md`](./target.md). Здесь — только «как
включить и убедиться, что крутится».

> Таргет `RP2040_BLDC_ODRIVE_CAN` — это альтернативная сборка той же
> платы **Raspberry Pi Pico / YD-RP2040**, на которой вместо двух
> BTS7960 (щёточный DC) живёт MCP2515+TJA1050 (SPI↔CAN мост) и пара
> ODrive на шине. Переключение — выбором `env` в PlatformIO (см.
> [`targets/README.md`](../README.md)), никаких #ifdef в `src/`.

## 1. Что нужно купить

| Кол-во | Что | Зачем | Заметки |
|---|---|---|---|
| 1 | Raspberry Pi Pico **или** YD-RP2040| MCU: RP2040, 125 МГц, 264 КБ SRAM, 2 МБ Flash | YD-RP2040 удобнее — onboard WS2812 + USB-C |
| 1 | Модуль MCP2515 + TJA1050 | SPI↔CAN, 5 В phy | Один из типовых модулей с кварцем 8 МГц |
| 2 | ODrive Pro / S1 / Micro | BLDC-контроллер, CAN 2.0B | Любой вариант с CAN-разъёмом |
| 1 | CRSF/ELRS-совместимый приёмник | Радиоканал RC (UART0) | TX на GP0, RX на GP1 |
| 1 | DC-DC 5 В (≥ 600 мА) | Питание MCP2515-модуля от Rail 12 В | Если модуль принимает только 5 В |
| 2 | BLDC-мотор + энкодер | Нагрузка на каждый ODrive | Поддерживается любая распиновка ODrive |
| 1 | USB-C кабель (data, не charge-only) | Прошивка через BOOTSEL + USB-CDC лог | |

Расходники: dupont-провода, терминаторы 120 Ω (обычно уже запаяны на
концах шины и переключаются на одном из ODrive DIP-переключателем),
блок питания 12–24 В под ODrive.

## 2. Схема подключения

ASCII-схема (только сигнальные линии; питание показано там, где важно).

```
                          ┌──────────────┐
   CRSF TX ─► GP0  UART0_TX┤              ├ GND
   CRSF RX ◄─ GP1  UART0_RX│              ├ GND
                          │              ├ VIN
                          │              ├ GND
                          │              ├ GP23 WS2812 (YD-RP2040)
       GP14 ─[резерв]─────┤              ├ GP22 IMU_INT1
       GP13 ─[резерв]─────┤              ├ GP21 I2C0_SCL
       GP12 ─[резерв]─────┤              ├ GP20 I2C0_SDA
        GND ──────────────┤              ├ 3V3(OUT)  ──┐ питание Pico
                          │   RP2040     ├ VREF         │
       GP9 ─[резерв]──────┤              ├ GP28 ADC2     │
       GP8 ─[резерв]──────┤              ├ GP27 ADC1     │
       GP7 ─[резерв]──────┤              ├ GP26 ADC0     │
       GP6 ─[резерв]──────┤              ├ GP29 ADC3     │
       GP5 ─[резерв]──────┤              ├ GP15 INT ◄─── MCP2515 INT (active LOW, 10k pull-up на модуле)
       GP4 ─[резерв]──────┤              ├ GP14 [резерв] │
       GP3 ─[резерв]──────┤              ├              │
       GP2 ─[резерв]──────┤              ├ GP19 MOSI ──► MCP2515 SI
                          │              ├ GP18 SCK ───► MCP2515 SCK
                          │              ├ GP17 CS ────► MCP2515 CS  (active LOW)
                          └──────USB─────┘ GP16 MISO ◄── MCP2515 SO
                                                                  │
                                            (по USB: BOOTSEL, USB-CDC лог)
                                       (по USB: питание 5 В)
```

### 2.1 MCP2515 ↔ Pico (SPI0)

| MCP2515 пин | RP2040 пин | Сигнал | Примечание |
|---|---|---|---|
| VCC | VBUS (5В) | Питание 5 В | Если модуль 5 В-толерантный; иначе через DC-DC 5 В и **проверить** VIO↔3V3 совместимость |
| GND | GND | Земля | Общая с ODrive-шиной |
| CS | GP17 | Чип-селект | GPIO OUT, active LOW |
| SCK | GP18 | SPI0 SCK | HW SPI0, Mode 0, MSB first, 7.8125 МГц |
| SI (MOSI) | GP19 | SPI0 MOSI | |
| SO (MISO) | GP16 | SPI0 MISO | |
| INT | GP15 | IRQ (вход) | MCP2515 INT, open-drain, на модуле уже подтянут к Vdd через 10 кОм |

Если модуль рассчитан на 3.3 В — подавайте `VCC` от `3V3(OUT)`, без
DC-DC, а землю объедините с общей.

### 2.2 MCP2515 ↔ ODrive-шина (CAN)

| MCP2515 | ODrive-CAN (оба контроллера параллельно) |
|---|---|
| CANH | CANH |
| CANL | CANL |
| GND | GND (общая земля с RP2040) |

```
   MCP2515/TJA1050                 ODrive #0 (LEFT, node_id=0)
   ┌──────────┐                    ┌────────────┐
   │ CANH ────┼────────────────────┼ CANH       │
   │ CANL ────┼────────────────────┼ CANL       │
   │ GND  ────┼────────────────────┼ GND        │
   └──────────┘                    └────────────┘
       │                               │
       │ 120 Ω                        │ 120 Ω   ← терминаторы на каждом конце шины.
       │                               │          на одном ODrive — DIP-переключателем,
       └───────────────────────────────┘          на MCP2515-модуле — RTERM-перемычкой
                                                  (если модуль на конце)
                  ODrive #1 (RIGHT, node_id=1)
                  ┌────────────┐
                  │ CANH       │
                  │ CANL       │
                  │ GND        │
                  └────────────┘
```

### 2.3 CRSF / ELRS (UART0)

| Pico | Приёмник ELRS/CRSF |
|---|---|
| GP0 (TX) | RX приёмника |
| GP1 (RX) | TX приёмника |
| GND | GND приёмника |
| VBUS/5V | +5V (или запитать от BEC'а ESC) |

### 2.4 ODrive-set_Limits на старте (важно для первого запуска)

Адреса узлов по умолчанию (в `target_config.h`):

- `BIBA_ODRIVE_LEFT_NODE_ID  = 0`
- `BIBA_ODRIVE_RIGHT_NODE_ID = 1`

Если платы уже настроены на другие ID — поменяйте обе константы
**до** первой прошивки либо перенастройте ODrive штатно (`<od> h`
по USB):

```
odrv0.axis0.motor.config.can_node_id = 0   # left
odrv1.axis0.motor.config.can_node_id = 1   # right
```

## 3. Сборка

Сборка делается через **PlatformIO** (CI-путь, основной) или **вручную
через CMake/Ninja/picotool** (для IDE / отладки).

### 3.1 PlatformIO — обычный путь

Из корня репозитория:

```bash
# PoC: только SPI↔MCP2515 self-test, без ODrive.
# Прошить первым делом на новой плате — проверяет SPI и питание.
pio run -e rp2040_bldc_odrive_can_loopback_poc
pio run -e rp2040_bldc_odrive_can_loopback_poc --target upload

# Продакшен-сборки:
pio run -e rp2040_bldc_odrive_can_standalone   # автономная логика (без SBC)
pio run -e rp2040_bldc_odrive_can_companion    # работает в паре с SBC по USB-CDC
pio run -e rp2040_bldc_odrive_can_combined     # режим выбирается MODE_SEL джампером

# Проверить, что UF2 собран, без прошивки:
pio run -e rp2040_bldc_odrive_can_loopback_poc --target size
```

`upload_protocol = picotool`, поэтому PlatformIO сам позовёт `picotool`.
Если он не в PATH — поставьте (`brew install picotool`,
`apt install picotool` или соберите из
[pico-sdk-tools](https://github.com/raspberrypi/picotool)).

### 3.2 CMake + Ninja + picotool — ручной путь (опционально)

Удобно для CLion / VS Code с CMake Tools. Готовый
`CMakeLists.txt` лежит прямо в таргете: [`CMakeLists.txt`](./CMakeLists.txt).

```bash
cd firmware/targets/RP2040_BLDC_ODRIVE_CAN
mkdir build && cd build
cmake -G Ninja -DPICO_SDK_PATH=/path/to/pico-sdk ..
ninja
picotool load -p /dev/ttyACM0 firmware.uf2
```

Требования к host'у: Pico SDK 1.5+ (на момент написания — 2.x),
`arm-none-eabi-gcc`, `picotool`, согласование `pico_enable_stdio_usb()`
(см. шапку `CMakeLists.txt`). Этот путь **не используется CI** — CI
гоняет только `pio run`.

## 4. Прошивка

Есть два пути; второй — запасной, если PlatformIO/picotool недоступны.

### 4.1 Автоматически (PlatformIO + picotool)

1. Зажать кнопку **BOOTSEL** на Pico.
2. Подключить USB-C к хосту.
3. Отпустить BOOTSEL — на хосте появится mass-storage `RPI-RP2`.
4. `pio run -e <env> --target upload` — PlatformIO сам переключит
   плату в нормальный режим и зашлёт UF2.

Одновременно с этим USB-CDC открывается как `/dev/ttyACM0` (Linux) /
`COMx` (Windows) — туда идёт `printf`-лог.

### 4.2 Ручной перетаскиванием UF2

1. Шаг 1–3 выше.
2. Из артефактов PlatformIO:
   ```bash
   ls .pio/build/rp2040_bldc_odrive_can_loopback_poc/firmware.uf2
   ```
3. `cp .pio/build/<env>/firmware.uf2 /media/$USER/RPI-RP2/`
4. Pico сама ребутнётся и начнёт исполнять код.

### 4.3 Что увидеть в логе (PoC, без ODrive)

После `can_loopback_poc` с подключённой шиной (но без ответчика) в
USB-CDC @ 115200 8N1 появляется:

```
[biba] RP2040_BLDC_ODRIVE_CAN CAN-loopback PoC
[biba] build: Jul 20 2026 17:12:34
[biba] target: RP2040_BLDC_ODRIVE_CAN @ 125 MHz, MCP2515 SPI @ 7812500 Hz
[biba] MCP2515 up @ 250000 bps
[biba] PoC running: TX Heartbeat @ 5 Hz, Set_Input_Vel @ 1 Hz
[biba] status t=... tx=... rx=0 rx_drop=0 q_rx_push=0 q_rx_pop=0 ...
```

`rx=0` без второго ODrive — это нормально. Если `MCP2515 init FAILED`
— проверяйте SPI-провода и питание модуля.

## 5. Конфигурация

В этом таргете **нет Kconfig / menuconfig** — это сознательное
решение, зафиксированное в ADR-0001 и согласованное с дисциплиной
[`targets/README.md`](../README.md). Переключение — выбор `env` в
PlatformIO, конфигурация — двумя header'ами рядом с этим README:

```
targets/RP2040_BLDC_ODRIVE_CAN/
├── target.h            # распиновка + capability-флаги BIBA_TARGET_HAS_*
├── target_config.h     # калибровки и лимиты
└── README.md           # ← этот файл
```

Допустимые ручки (все — через `#define`):

**Распиновка — `target.h`.** Изменять только если вы переносите
прошивку на другой клон Pico или распиновка именно вашей ревизии
YD-RP2040 конфликтует.

**Лимиты / адреса — `target_config.h`.** Вот что типично правится при
первом запуске:

| Макрос | Что меняет | Дефолт |
|---|---|---|
| `BIBA_ODRIVE_LEFT_NODE_ID` | CAN-ID левого ODrive | `0` |
| `BIBA_ODRIVE_RIGHT_NODE_ID` | CAN-ID правого ODrive | `1` |
| `BIBA_ODRIVE_LEFT_DIR` | Полярность колеса: `1.0f` или `-1.0f` | `1.0f` |
| `BIBA_ODRIVE_RIGHT_DIR` | Полярность колеса | `1.0f` |
| `BIBA_ODRIVE_LEFT_MAX_VEL_REV_S`  | Макс. скорость левого при `duty = ±1.0` (rev/s) | `6.0f` (~360 RPM на колесе) |
| `BIBA_ODRIVE_RIGHT_MAX_VEL_REV_S` | Макс. скорость правого | `6.0f` |
| `BIBA_ODRIVE_MAX_CURRENT_A` | Лимит тока, едет в ODrive через `Set_Limits` | `30.0f` |
| `BIBA_ODRIVE_MAX_VEL_LIMIT_REV_S` | Жёсткий ceiling, отправляется через `Set_Limits` | `10.0f` |
| `BIBA_CAN_BITRATE_BPS` | Битрейт CAN-шины | `250000u` |
| `BIBA_ODRIVE_HEARTBEAT_TIMEOUT_MS`| Через сколько ms без Heartbeat'а прекращаем слать `Set_Input_Vel` | `250` |
| `BIBA_ODRIVE_SETPOINT_RATE_HZ` | Частота `Set_Input_Vel` | `50` |
| `BIBA_SYS_CLOCK_HZ` | Тактовая RP2040 (менять не надо) | `125000000u` |

Capability-флаги в `target.h` (менять, только если понимаете
последствия):

| Макрос | Значение | Что значит |
|---|---|---|
| `BIBA_TARGET_HAS_BTS7960_2CH` | `0` | BTS7960 не распаян, brushed backend выключен |
| `BIBA_TARGET_HAS_BLDC_2CH` | `1` | BLDC-backend включён |
| `BIBA_TARGET_HAS_MCP2515` | `1` | SPI↔CAN-мост есть |
| `BIBA_TARGET_HAS_CRSF` | `1` | CRSF/ELRS на UART0 |
| `BIBA_TARGET_HAS_IMU` | `1` | I2C0 IMU (GP20/21) |
| `BIBA_TARGET_HAS_SPI_SLAVE` | `0` | SBC по USB-CDC, не по SPI |
| `BIBA_TARGET_HAS_PER_CHANNEL_TIMER_PWM` | `0` | ШИМ не разведён (не используется) |

## 6. Проверка после прошивки

Пошагово, минимально-достаточно чтобы понять «живо/не живо»:

1. **Boot-логи.** Откройте USB-CDC терминал на 115200 8N1. Должны
   увидеть строки `[biba] RP2040_BLDC_ODRIVE_CAN …` и `[biba] MCP2515 up
   @ 250000 bps`. Если `MCP2515 init FAILED (status=-N)` — нет связи
   по SPI (проверьте провода MISO/SCK/MOSI/CS и питание модуля).

2. **CAN discover.** Подайте питание на ODrive (12–24 В), дождитесь
   их boot-up. При физической шине с двумя ответчиками в логе
   должны появиться RX-кадры от ODrive:

   ```
   [can] RX id=0x001 dlc=7 data= 08 00 00 00 00 00 00 00  ← heartbeat node 0
   [can] RX id=0x021 dlc=7 data= 08 00 00 00 00 00 00 00  ← heartbeat node 1
   ```

   Heartbeat-формат: dlc=7, data[0] = axis state (0x08 = closed loop).

3. **Drive.** Включите передатчик, газ в нейтрали — статус LED
   (GP25) должен моргать/гореть постоянно (означает «heartbeat
   идёт»), RGB-LED (GP23) — режим idle. Дайте ~10 % газа: левый
   ODrive должен крутить левое колесо вперёд, правый — правое.
   Если одно колесо идёт в обратную сторону — переверните
   соответствующий `BIBA_ODRIVE_*_DIR` в `target_config.h`.

4. **Failsafe.** Выключите питание ODrive (но не Pico). В течение
   `BIBA_ODRIVE_HEARTBEAT_TIMEOUT_MS` (250 мс по умолчанию)
   firmware перестанет слать `Set_Input_Vel`; ODrive сам disarm'нется
   по своему watchdog (100 мс). Лог покажет
   `biba_bldc_node_alive(0) == false`.

## 7. Минимальный пример обмена

Полный рабочий пример лежит в
[`../../src/poc/can_loopback_poc.cpp`](../../src/poc/can_loopback_poc.cpp).
Здесь — сжатый фрагмент «как отправить Set_Input_Vel и как
прочитать Heartbeat» из этого PoC'а — для C/C++, ровно как в этом
проекте:

```c
#include "drivers/mcp2515.h"
#include "drivers/odrive_can.h"

/* Формирование CAN-ID по CANSimple: (node_id << 5) | cmd_id,
 * 11 бит, big-endian bit-fields внутри 32-битного поля id. */
static inline uint32_t can_id(uint8_t node_id, uint8_t cmd_id) {
    return ((uint32_t)(node_id & 0x3Fu) << 5u) | (uint32_t)(cmd_id & 0x1Fu);
}

static void pack_f32_le(uint8_t *dst, float v) {
    union { float f; uint32_t u; } x = { .f = v };
    for (int i = 0; i < 4; ++i) dst[i] = (uint8_t)((x.u >> (8u * i)) & 0xFFu);
}

/* 1) Init — один раз, в setup(). */
biba_mcp2515_status_t st = biba_mcp2515_init();   /* 250 kbps, 87.5 % sample point */
biba_can_queue_rx_init();
biba_can_queue_tx_init();
biba_bldc_init();  /* отправит Set_Axis_State=CLOSED_LOOP + Set_Limits */

/* 2) Set_Input_Vel: 8 байт, [0..3] = velocity float LE, [4..7] = torque_ff float LE. */
static void send_set_input_vel(uint8_t node_id, float vel_rev_s, float torque_ff_nm) {
    uint8_t payload[8];
    pack_f32_le(&payload[0], vel_rev_s);
    pack_f32_le(&payload[4], torque_ff_nm);
    biba_can_frame_t f = {
        .id  = can_id(node_id, OD_CMD_SET_INPUT_VEL),  /* 0x0D */
        .dlc = 8,
    };
    memcpy(f.data, payload, sizeof(payload));
    (void)biba_mcp2515_tx(&f);
}

/* 3) Главный цикл (50 Гц): */
void loop_50hz(void) {
    float throttle = 0.0f;  /* из CRSF: [-1.0, +1.0] */
    /* duty → velocity: умножаем на BIBA_ODRIVE_*_MAX_VEL_REV_S из target_config.h */
    send_set_input_vel(BIBA_ODRIVE_LEFT_NODE_ID,
                       throttle * BIBA_ODRIVE_LEFT_MAX_VEL_REV_S * BIBA_ODRIVE_LEFT_DIR,
                       0.0f /* torque_ff */);
    send_set_input_vel(BIBA_ODRIVE_RIGHT_NODE_ID,
                       throttle * BIBA_ODRIVE_RIGHT_MAX_VEL_REV_S * BIBA_ODRIVE_RIGHT_DIR,
                       0.0f);

    /* 4) Дренаж RX: декодирует Heartbeat, Get_Iq, Get_Bus_Voltage_Current и т. д. */
    biba_bldc_tick_50hz();
}
```

Если на шине есть второй ODrive, в RX-очереди будут появляться
Heartbeat'ы:

```
id=0x001 dlc=7 data= 08 00 00 00 00 00 00
  │  │    │    └─── [0] axis state (0x08 = CLOSED_LOOP_CONTROL)
  │  │    └─────── data length
  │  └──────────── 0x001 = (node_id 0 << 5) | cmd_id 0x01 (HEARTBEAT)
  └─────────────── CAN ID
```

Узел жив, если `biba_bldc_node_alive(node_id) == true`. Возвращает
`false` через `BIBA_ODRIVE_HEARTBEAT_TIMEOUT_MS` без кадров.

## 8. Решение типовых проблем

| Симптом | Скорее всего |
|---|---|
| `MCP2515 init FAILED (status=-1)` `BIBA_MCP2515_ERR_SPI` | SPI peripheral не поднялся — кварц 8 МГц не идёт, пропало питание модуля, либо GP16/18/19 не заведены как SPI0 |
| `MCP2515 init FAILED (status=-2)` `BIBA_MCP2515_ERR_RESET`  | RESET instruction не отвечает — CS не дёргается (проверьте GP17, уровень на нём HIGH в покое), либо MISO/MOSI перепутаны |
| `MCP2515 init FAILED (status=-3)` `BIBA_MCP2515_ERR_CONFIG` | CNF1/CNF2/CNF3 не принимаются — чип уже в Normal, либо lock-бит не сброшен после warm-reset (выключите-включите питание MCP2515) |
| `rx=0 rx_drop=N` при живых ODrive | Терминаторы (120 Ω на обоих концах), земля общая |
| Один мотор идёт в обратную сторону | Поменяйте `BIBA_ODRIVE_{LEFT,RIGHT}_DIR` в `target_config.h` |
| Моторы дёргаются | Лимиты `BIBA_ODRIVE_MAX_CURRENT_A` слишком мягкие / питание проседает |
| Heartbeat'ы не приходят, ошибки декодера растут | Битрейт не совпадает (`BIBA_CAN_BITRATE_BPS` vs `odrvN.can.config.bitrate`) |
| PoC не печатает ничего в CDC | USB-кабель без data; либо 300 ms ещё не прошли (USB-CDC enum) |

## 9. Куда смотреть дальше

- [`target.md`](./target.md) — детальная распиновка по группам
  периферии и «что убрано по сравнению с RP2040_DC_BTS7960_PWM».
- [`../../src/poc/can_loopback_poc.cpp`](../../src/poc/can_loopback_poc.cpp) —
  самый короткий путь «увидеть байты в шине» без ODrive.
- [`../../../docs/adr/0001-pico-bldc-target.md`](../../../docs/adr/0001-pico-bldc-target.md) —
  ADR с обоснованием выбора SPI/HW/MCP2515 и почему нет Kconfig.
- [`../../../docs/mcp2515_bldc_research.md`](../../../docs/mcp2515_bldc_research.md) —
  полный research: питание модуля, терминаторы, ODrive CANSimple,
  полная таблица cmd_id.
- [`../RP2040_DC_BTS7960_PWM/target.md`](../RP2040_DC_BTS7960_PWM/target.md) — если нужно
  сравнить со щёточным вариантом на той же плате.

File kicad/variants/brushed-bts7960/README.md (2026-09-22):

# Вариант 1: коллекторные моторы + BTS7960 (`brushed-bts7960`)

Статус: **ревизия после разбора отказа U2**. Импорт из EasyEDA закрыт,
сверху внесена доработка по [analysis/M1-driver-failure.md](analysis/M1-driver-failure.md) §5:
керамика по питанию драйверов, DC-link, снабберы и супрессоры на выходах,
альтернативный DC/DC. Плата выросла до 180.5 × 100.3 мм.

## Что это

Первый (основной) вариант привода BiBa: два коллекторных редукторных мотора
**MY1016Z**, управляемые двумя модулями **BTS7960**, под управлением платы
**RP2040** (YD-RP2040 / RPi Pico-класс).

## Источник истины

- Таргет: `firmware/targets/RP2040_DC_BTS7960_PWM/` — `target.md` (распиновка), `target.h` (пины).
- Варианты: `docs/variants.md`.
- Шасси: `firmware/tools/cad/sbiba_chassis.py` — MY1016Z 24 В / 250 Вт,
  колесо насаживается прямо на выходной вал редуктора.

## Gerber-анализ (архив 2026-05-27)

Исходник: `Gerber_RP2040_PCB_RP2040_2026-05-27.zip` — экспорт из **EasyEDA**
(`How-to-order-PCB.txt` ссылается на docs.easyeda.com). Двухслойная плата,
нетлиста (IPC-356) в архиве **нет** → схема из гербера напрямую не
восстанавливается (в герберах только разводка и шелкография, без номиналов
и соединений на уровне схемы).

Отрендеренные слои: `gerber/render/` (рендер — `scripts/gerber_render.py`,
через pygerber). Состав платы по меди + шелкографии:

- Слева: посадочное место **RP2040-модуля** (два ряда площадок) + разъём `MPU` (J7).
- Центр: аналоговая обвязка **U1 + RC** (R4–R24, C1–C12) — RC-фильтры и делители.
- Справа: два силовых блока **BTS7960** (M1, M2), толстые токовые дорожки.
- Разъёмы: `UART1` (RX/TX/+5V/SW), `CRSF` (+/−/TX/RX), `BAT`, площадка приёмника `2.4 GHz`.
- Низ: GND-полигон + сигнальная разводка, сквозные переходные.

## Восстановленная схема (из EasyEDA-исходника)

Исходник EasyEDA лежит в `easyeda/RP2040/` (`RP2040.json` — схема,
`PCB_RP2040.json` — плата). Из него восстановлены **57 компонентов и 56 сетей**:

- `easyeda/RP2040/netlist.txt` — полный нетлист (сеть → пины).
- `easyeda/RP2040/components.tsv` — список компонентов (обозначение, номинал, корпус, LCSC).
- Парсер: `scripts/easyeda_netlist.py`.

Архитектура (точнее, чем в `target.md`):

- **Питание:** VIN (24 В) → C9 1000 мкФ → **PM1 SKMW30G-05** (24→5 В) → +5V;
  +5V → **U7 SPX3819M5-L-3-3** (5→3.3 В) → 3.3V.
- **MCU:** IC1 — RP2040 breakout (44 пина), распиновка совпадает с `target.h`.
- **Драйверы моторов:** **4× BTN7970** (U2–U5), по два полумоста на мотор
  (левый: U2 high + U3 low; правый: U4 high + U5 low). Выходы M1+/M1− и M2+/M2−.
- **Буфер:** U1 **SN74AHC244DW** — 8 линий PWM/EN от RP2040 → IN/INH драйверов.
- **IMU:** U6 **BMI160** на I2C0 (GP20/GP21) + INT на GP22, подтяжки R22/R23 10 кОм.
- **Токовый сенс:** IS драйверов → R17–R20 (1 кОм) → R_IS/L_IS → RC (C2/C3 0.1 мкФ)
  → IC1.31/32; R11–R16 (10 кОм) — подтяжки IS к GND.
- **VBAT/IBAT:** R26/R25 (1 кОм) → IC1.34/35; разъём H10 (GND/VBAT/IBAT).
- **Периферия:** J3 CRSF (+5V/GND/TX/RX), J4 UART1 (+5V/GND/TX/RX);
  свободные GP10–GP19 выведены на H1–H8 (1×3: GPIO, +5V, GND).
- **Включение:** J2 (SW/GND/+5V/GND) — управление DC/DC; J1 (+5V/PM1_4/GND).

## Состав (блок-схема)

```mermaid
flowchart LR
    BAT["Батарея 24 В<br/>(Daly BMS)"] --> VBAT["Делитель VBAT<br/>GP28 (ADC2)"]
    BAT --> IBAT["Датчик тока батареи<br/>GP29 (ADC3)"]
    BAT --> DCDC["DC/DC 24→5 В<br/>(панели, плата)"]
    BAT --> BTS_L["BTS7960 (левый)"]
    BAT --> BTS_R["BTS7960 (правый)"]
    RP["Плата RP2040"] -- "RPWM/LPWM + REN/LEN" --> BTS_L
    RP -- "RPWM/LPWM + REN/LEN" --> BTS_R
    BTS_L -- "IS (RC-фильтр)" --> RP
    BTS_R -- "IS (RC-фильтр)" --> RP
    BTS_L --> M_L["MY1016Z 24 В / 250 Вт (левый)"]
    BTS_R --> M_R["MY1016Z 24 В / 250 Вт (правый)"]
    CRSF["Приёмник CRSF/ELRS"] <-->|"UART0 (GP0/GP1)"| RP
    IMU["IMU BMI160 / LSM6DS3"] <-->|"I2C0 (GP20/GP21) + INT (GP22)"| RP
    SBC["Одноплатник"] <-->|"UART1 (GP12/GP13)"| RP
    RP --> RGB["RGB WS2812 (GP23, onboard)"]
    RP --> PANEL["LED-панели 2×4×4 (GP14)"]
```

## Распиновка RP2040 (из `target.h`)

| GP  | Функция | Сигнал | Направление | Примечание |
|-----|---|---|---|---|
| GP0 | UART0_TX | CRSF TX | ВЫХ | к RX приёмника |
| GP1 | UART0_RX | CRSF RX | ВХ | от TX приёмника |
| GP2 | PWM1A | L_RPWM | ВЫХ ШИМ | слайс 1, канал A |
| GP3 | PWM1B | L_LPWM | ВЫХ ШИМ | слайс 1, канал B |
| GP4 | GPIO OUT | L_REN | ВЫХ | enable правого полумоста (левый драйвер) |
| GP5 | GPIO OUT | L_LEN | ВЫХ | enable левого полумоста (левый драйвер) |
| GP6 | PWM3A | R_RPWM | ВЫХ ШИМ | слайс 3, канал A |
| GP7 | PWM3B | R_LPWM | ВЫХ ШИМ | слайс 3, канал B |
| GP8 | GPIO OUT | R_REN | ВЫХ | enable правого полумоста (правый драйвер) |
| GP9 | GPIO OUT | R_LEN | ВЫХ | enable левого полумоста (правый драйвер) |
| GP10–GP11 | — | free | — | свободны |
| GP12 | UART1_TX | SBC TX | ВЫХ | RP2040 → одноплатник |
| GP13 | UART1_RX | SBC RX | ВХ | одноплатник → RP2040 |
| GP14 | PIO OUT | LED_PANEL | ВЫХ | цепочка WS2812: GP14 → левая → правая |
| GP15 | — | free | — | свободен |
| GP16–GP19 | — | free | — | свободны (SPI0/I2C1/UART0 по выбору) |
| GP20 | I2C0_SDA | IMU SDA | I/O | |
| GP21 | I2C0_SCL | IMU SCL | ВЫХ | |
| GP22 | GPIO IN | IMU INT1 | ВХ | прерывание IMU |
| GP23 | WS2812 | RGB_LED | ВЫХ | NeoPixel на YD-RP2040 |
| GP25 | GPIO OUT | STATUS_LED | ВЫХ | встроенный LED Pico, активный HIGH |
| GP26 | ADC0 | IS_RIGHT | ВХ | RC-фильтр 1 кΩ‖1 кΩ + 0.1 µF от IS правого BTS7960 |
| GP27 | ADC1 | IS_LEFT | ВХ | RC-фильтр 1 кΩ‖1 кΩ + 0.1 µF от IS левого BTS7960 |
| GP28 | ADC2 | VBAT | ВХ | делитель напряжения, коэфф. `BIBA_VBAT_DIVIDER_RATIO` |
| GP29 | ADC3 | IBAT | ВХ | выход датчика тока батареи |

## Силовые цепи

- Шина **24 В** — батарея (Daly BMS) → оба BTS7960, датчик тока батареи,
  вход DC/DC 24→5 В.
- Шина **5 В** — питание LED-панелей и Vin платы RP2040
  (панели в худшем случае ~0.9 А на 32 светодиода, белый на ходу).
- Шина **3V3** — логика (с платы RP2040), IMU, приёмник CRSF.
- Общая земля силовой и логической частей (как в `docs/wiring.md`).

## Измерения (АЦП)

| Канал | Пин | Сигнал | Калибровка |
|---|-----|---|---|
| ADC0 | GP26 | IS_RIGHT | RC 1 кΩ‖1 кΩ + 0.1 µF от IS-пинов BTS7960 |
| ADC1 | GP27 | IS_LEFT | RC 1 кΩ‖1 кΩ + 0.1 µF от IS-пинов BTS7960 |
| ADC2 | GP28 | VBAT | `BIBA_VBAT_DIVIDER_RATIO = 10.12` (калибровано 2026-05-26) |
| ADC3 | GP29 | IBAT | `BIBA_IBAT_AMPS_PER_VOLT = 1.0`, `BIBA_IBAT_ZERO_OFFSET_V = 0.0` |

Ключевые константы из `firmware/include/biba_config.h`:

- `BIBA_PWM_FREQUENCY_HZ = 20000` (несущая 20 кГц, выше слышимого).
- `BIBA_CONTROL_LOOP_HZ = 500`, `BIBA_TELEMETRY_PUBLISH_HZ = 200`.
- Левый/правый PWM-канал делят один слайс (фиксированный wrap) —
  независимые несущие на канал не поддерживаются
  (`BIBA_TARGET_HAS_PER_CHANNEL_TIMER_PWM = 0`).

## BOM (черновик)

| # | Компонент | Кол-во | Примечание |
|---|---|---|---|
| 1 | Плата RP2040 (YD-RP2040, USB-C, 2 МБ Flash) | 1 | совместима с RPi Pico |
| 2 | Модуль BTS7960 43A dual H-bridge | 2 | по одному на мотор |
| 3 | Мотор MY1016Z 24 В / 250 Вт, редукторный | 2 | левый/правый, колесо на валу |
| 4 | Приёмник CRSF/ELRS | 1 | UART0 (GP0/GP1) |
| 5 | IMU (BMI160 или LSM6DS3-class) | 1 | I2C0 (GP20/GP21), INT на GP22 |
| 6 | Батарея 24 В + Daly BMS | 1 | силовая шина |
| 7 | Резисторный делитель VBAT | 1 | коэфф. 10.12 → GP28 |
| 8 | Датчик тока батареи (IBAT) | 1 | выход на GP29 |
| 9 | RC-фильтры IS: 1 кΩ‖1 кΩ + 0.1 µF | 2 | IS BTS7960 → GP26/GP27 |
| 10 | RGB WS2812 | 1 | onboard YD-RP2040 (GP23) |
| 11 | LED-панели WS2812 4×4 | 2 | цепочка GP14 → левая → правая |
| 12 | DC/DC 24→5 В | 1 | питание панелей и платы |

## Известные риски

- **Тепловой режим BTS7960** — известное слабое место под длительной
  нагрузкой (старт/стоп/реверс дают 3–10× номинал тока). См.
  `.planning/phases/04-thermal-hardening/` — учитывать радиаторы/обдув
  и токовую защиту при проектировании платы.
- Термо-защита снимается импульсом на `REN`/`LEN` (100 мкс LOW), PWM при
  этом должен оставаться нулём. См. `.planning/phases/03-field-ready/`.
- **Отказы драйвера U3 («M1 задний ход») на плате RP2040** — разбор обвязки
  BTN7970, трассировки и прошивки: [`analysis/M1-driver-failure.md`](analysis/M1-driver-failure.md).

## Открытые вопросы (решить при отрисовке схемы)

1. Тип датчика IBAT (ACS712 / INA226 / шунт+усилитель) — уточнить по факту.
2. Предохранители на линии 24 В моторов (номинал, плавкие/автомат).
3. Разъёмы: батарея (XT60/XT30?), моторы, приёмник, IMU, SBC.
4. Интерфейс BMS (Daly BLE/UART) — выводить ли на плату.
5. Разводка GP29/IBAT: калибровочные коэффициенты по конкретному датчику.

## KiCad-проект (сгенерирован автоматически)

Импорт из EasyEDA закрыт целиком: и схема, и плата.

| Файл | Что это |
|---|---|
| `brushed-bts7960.kicad_pro` | проект (классы цепей перенесены из `DRCRULE` EasyEDA) |
| `brushed-bts7960.kicad_sch` | схема: 69 компонентов, 58 цепей (импорт 1:1 = 57/56, плюс доработка ниже) |
| `brushed-bts7960.kicad_pcb` | плата 180.51 × 100.33 мм, 2 слоя, 69 компонентов (импорт был 124.51 × 100.33) |
| `sym-lib-table` / `fp-lib-table` | таблицы библиотек |
| `kicad/common/symbols/biba.kicad_sym` | символы |
| `kicad/common/footprints/biba.pretty/` | 14 футпринтов, выгруженных с платы |

Генераторы (импорт **разовый** — оба откажутся затирать существующий файл
без `--force`, потому что схема и плата дальше ведутся в KiCad):

```
python scripts/easyeda_sch2kicad.py kicad/variants/brushed-bts7960   # схема
python scripts/gen_pcb.py           kicad/variants/brushed-bts7960   # плата
```

`gen_pcb.py` требует Python из состава KiCad (модуль `pcbnew`) — находит его
сам, при нестандартной установке задайте `KICAD_HOME`. Плату импортирует
штатный конвертер `kicad-cli pcb import` (формат EasyEDA / JLCEDA Std),
свой парсер платы не пишем.

### Что проверено

- **Связность совпадает с исходником EasyEDA побитово**: 56 сетей,
  220 пин-назначений, расхождений нет.
- **Схема и плата сходились 1:1 на момент импорта**: все 56 цепей совпали
  по составу пинов, одинаковый набор из 57 обозначений, футпринт в схеме
  равен футпринту на плате, все ссылки `biba:*` разрешаются в `biba.pretty`.
  Расходились только имена 12 неподписанных цепей (KiCad зовёт их
  `Net-(U2-IS)`, EasyEDA звал `U2_6`) — на связность это не влияет.
  После доработки ниже схема опережает плату на 11 компонентов.
- **DRC: 0 неразведённых пар**, гербера и сверловка экспортируются.
- ERC: 2 ошибки `power_pin_not_driven` (`+5V` и `GND` не имеют
  power-output пина). Это было и до импорта платы — лечится расстановкой
  `PWR_FLAG` в схеме.

### Оставшиеся замечания DRC (555, все — свойства исходника)

| Кол-во | Проверка | Почему так |
|---|---|---|
| 199 | `pth_inside_courtyard` | массивы переходных падов под силовыми выходами заходят в courtyard U2–U5 — так и задумано |
| 185 + 49 + 28 + 1 | `silk_*`, `text_height` | шелкография EasyEDA: подписи наезжают друг на друга и на медь |
| 64 | `padstack` | у пассивов 0805/0603 в EasyEDA выставлено расширение пасты −100 мм, т.е. «паяльной пасты нет». В оригинальном `Gerber_TopPasteMaskLayer.GTP` апертур под эти пады действительно нет — перенесено как есть |
| 22 | `lib_footprint_mismatch` | одноимённые футпринты в исходнике расходятся на доли микрона и сдвинутыми подписями; эталоном берётся самый массовый экземпляр |
| 7 | `starved_thermal` | термо-развязка в один луч вместо двух (правила KiCad строже, чем у EasyEDA) |

Два полигона (`VIN` F.Cu и `GND` B.Cu) пустые — у них вырожденный контур
в самом исходнике EasyEDA (площадь 0 и 0.5 мм²). Оставлены как есть.

### Чего импорт не переносит

- **Правила DRC** — переносит уже `gen_pcb.py` (зазор 0.152 мм,
  дорожка 0.254 мм, via 0.61/0.305 мм; отдельный класс `5v` — дорожка 0.5 мм).
  Без этого плата осталась бы с дефолтами KiCad (зазор 0.2 мм), под которые
  она не разводилась.
- **Заливку полигонов** — импортёр переносит контуры без вырезов под чужие
  цепи, поэтому `gen_pcb.py` перезаливает их штатным `ZONE_FILLER`
  (иначе DRC показывает ~900 ложных пересечений).
- **3D-модели** — `kicad/common/3dmodels/` пуст.

### Свободные пады и отверстия

EasyEDA держит вне компонентов 425 объектов, KiCad заводит под них
псевдо-футпринты `Pad_ggeNNNN` / `Hole_ggeNNNN`. Все помечены board-only
(мимо BOM и pos-файлов). Состав:

- 400 падов 0.61/0.3 мм на `M1±`/`M2±` — токовые переходные массивы;
- 12 падов 1.0/0.6 мм на `GND` — сшивка земли;
- 6 падов 5×4 мм со сверловкой 2 мм — силовые клеммы `VIN`, `GND`, `M1±`, `M2±`;
- 5 отверстий 3.2 мм NPTH — крепёж;
- 2 пада 2.0/0.91 мм — отводы `+5V` и `GND`.

### Доработка после импорта (2026-09-21)

В схему добавлен блок защиты и развязки по
[`analysis/M1-driver-failure.md`](analysis/M1-driver-failure.md) §5 —
подробности и обоснование номиналов в §5a того же документа:

- **C10–C13** 470 нФ X7R 50 В — керамика VS–GND у каждого драйвера U2–U5 (§5.1);
- **C14** 1000 мкФ 50 В low-ESR — DC-link у пары U2/U3, где его не хватало (§5.2);
- **R27+C15**, **R28+C16** 22 Ом 5 Вт + 100 нФ 100 В плёнка — RC-снабберы
  между выходами каждого моста, M1+/M1− и M2+/M2− (§5.7);
- **D1, D2** 1.5KE30CA — супрессоры на выводах моторов, параллельно снабберам.

Шина VIN при этом осталась без супрессора — §5.3 анализа и статья просят TVS
именно там. Закрывается третьим корпусом (D3) на VIN–GND у клеммы.

Стало: 68 компонентов, 58 цепей (добавились `M1_SNUB`, `M2_SNUB`). ERC без
новых замечаний. Для TVS заведён символ `biba:TVS_BIDIR`; футпринты
выводных деталей взяты из стандартных библиотек KiCad (`Diode_THT`,
`Resistor_THT`, `Capacitor_THT`) — они резолвятся через глобальную
`fp-lib-table`, в проектную ничего добавлять не нужно.

Заодно метка цепи в схеме переименована `Vin` → `VIN`: имена сетей в KiCad
регистрозависимы, а на плате и во всей документации цепь называется `VIN`.

### Ревизия платы (2026-09-21)

Доработка перенесена на плату. **Плата выросла: 124.51 × 100.33 → 180.51 ×
100.33 мм** (+56 мм вправо). Снабберные резисторы 5 Вт — выводные 25×9 мм с
шагом 30.5 мм, на старую плату они не помещались нигде: ближайшее свободное
место было в 48 мм от клемм мотора, что смысл снаббера убивает.

Новая полоса справа от клемм:

Компоненты стоят вертикальными колонками: супрессор у самых клемм
(x≈216), за ним мощный резистор (x≈226), за ним плёнка (x≈236).
Мощные резисторы развёрнуты вертикально — так полоса по горизонтали
освобождается под PM2.

| Группа | Состав | Расположение |
|---|---|---|
| M1 | D1, R27, C15 | y 50…84 |
| M2 | D2, R28, C16 | y 86…120 |
| Питание | PM2 (альтернативный DC/DC) | x 240…267, y 60…112 |

Шины M+ и M− идут параллельно и нигде не пересекаются: от клеммы к
супрессору поверху, дальше через резистор к плёнке и обратно понизу.

PM2 сдвинут влево и целиком помещается на плате. В первой раскладке он
стоял у правого края, и его корпус (52.4 мм при рядах выводов 20.32 мм)
вылезал за контур на 8 мм — пады были внутри, а тело нет.

**PM2 — альтернативный DC/DC Mean Well NSD10-48S5** (22–72 В → 5 В / 2 А,
DIP-6, футпринт `Converter_DCDC_MeanWell_NSD10_THT` из стандартной
библиотеки KiCad). У него **свои отверстия**, не общие с PM1: назначение
выводов 3/4/5 у модулей разное (у SKMW30G-05 на выводе 3 плюс выхода, у
NSD10 — минус), поэтому общая разводка сожгла бы NSD10. Каждый модуль
разведён по своему даташиту, ставится **один из двух**.

Керамика C10–C13 стоит слева от выводов драйверов (под корпусом TO-263
места нет), пад GND заведён переходным отверстием на нижний GND-полигон.
C14 1000 мкФ — вверху, симметрично C9.

Схема и плата сходятся: 69 компонентов с обеих сторон, все 58 цепей
совпадают по составу пинов.

### Силовая часть: стекап и земля драйверов

Стекап задан явно — **медь 70 мкм (2 oz)** на обоих слоях, FR-4 1.51 мм,
ENIG. Плата и так делается на 2 oz, но в файле была только общая толщина
1.6 мм, и вес меди оставался догадкой: любой расчёт по геометрии висел в
воздухе.

По расчёту (`scripts/pcb_power_check.py`, разбор — §7 анализа) дорожка M±
шириной 4 мм на 2 oz даёт 20.9 А при перегреве +45 °C, то есть ровно
номинал мотора без запаса на пуск. Поэтому:

- силовым выводам U2–U5 (1 GND, 7 VS, таб) и клеммам VIN/GND/M1±/M2±
  задано **сплошное подключение к полигону** вместо тепловых спиц;
- у вывода 1 каждого драйвера добавлены переходные по GND (было 3 на
  драйвер, стало 5–6), с дорожкой 0.6 мм к паду. Всего переходных GND 22.

Ошибок `starved_thermal` стало 7 → 2 (оставшиеся у IC1, не силовые).

У PM2 разведены VIN (вывод 1) и GND (выводы 2 и 3) — короткими трассами
от силовых клемм.

**Что осталось развести вручную** (6 связей, видны как ratsnest в pcbnew):

- **+5V и SW у PM2.** Эти две цепи идут через всю плату к PM1 (+5V на
  PM1.3, SW на PM1.6) — около 110 мм каждая. Автоматический поиск пути по
  нижнему слою их находит (158 и 191 мм с обходами), но получившиеся два
  длинных выреза **разрезают GND-полигон надвое**: в DRC сразу появляются
  два изолированных островка GND и лишние `starved_thermal`. Это ровно тот
  дефект, который разбирается в §3.4 анализа, поэтому такой вариант
  отброшен. Нужно либо вести их по верхнему слою с ручной укладкой, либо
  принять разрез осознанно и провести его по краю платы.
- **VIN у C10, C11, C12** — прямая трасса к выводу 7 драйвера режет веер
  сигнальных выводов 2–6. Нужен обход низом или ручная трасса. У C13 путь
  был свободен, он разведён.
- Один островок GND у вывода 1 U4.

### Повторный импорт

Библиотека футпринтов и схема генерируются детерминированно — повторный
запуск даёт побайтово тот же результат. А вот сам `.kicad_pcb` конвертер
KiCad каждый раз пересобирает заново (новые UUID, другой порядок объектов),
поэтому перезапуск `gen_pcb.py` даёт огромный diff при нулевых изменениях
по сути. Плату после импорта правим в KiCad; `gen_pcb.py` перезапускаем
только если поменялся исходник `easyeda/RP2040/PCB_RP2040.json`.

## Дальнейшие шаги

1. **Дорастить 6 оставшихся связей** в pcbnew: VIN у C10–C12, +5V и SW у PM2,
   островок GND у U4 (см. раздел про ревизию платы выше).
2. Решить по супрессору на шине VIN (§5.3): добавить D3 или оставить как есть.
3. Расставить `PWR_FLAG` в схеме — закрыть 2 ошибки ERC.
4. Остальные пункты §5 анализа, не вошедшие в эту правку: U1 → AHCT244 (5.4),
   R_SR (5.5), R_IS (5.6), pull-down на входах U1 (5.8), тормозной чоппер (5.9).
5. Разобрать шелкографию (234 предупреждения) — перенос подписей.
6. Решить по 0805/0603: оставить их без паяльной пасты или вернуть апертуры.
7. Подтянуть 3D-модели в `kicad/common/3dmodels/`.
8. Экспорт герберов/BOM для производства из KiCad вместо архива EasyEDA.

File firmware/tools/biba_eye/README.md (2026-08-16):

# BIBA Eye

FPV-инструмент для камеры **V380 Q8** (и аналогичных): веб-страница с живым
видео и управлением поворотом камеры (PTZ) с клавиатуры или кнопок.

## Возможности
- 🎥 Видео в браузере (RTSP → MJPEG через ffmpeg, ~20 к/с)
- 🕹 PTZ: **WASD / стрелки** (держать — движение, отпустить — стоп), кнопки на экране
- ⚙️ **Первый запуск**: страница спрашивает IP камеры или сама находит камеры в сети
- 📶 **Профили качества**: Ultra (макс. скорость) / Fast / Balanced / Quality (720p) — выбор в шапке, переключение на лету
- 💾 Всё сохраняется в `config.json`, повторный запуск — без ввода

## Установка одной строкой
Скопируйте и выполните в PowerShell (скачает всё с GitHub и настроит ПК):
```powershell
irm https://raw.githubusercontent.com/GOODWORKRINKZ/biba/main/firmware/tools/biba_eye/install.ps1 | iex
```
Локальный вариант (если папка тулзы уже есть рядом):
```powershell
powershell -ExecutionPolicy Bypass -File tools\biba_eye\setup.ps1
```
Скрипт сам:
- установит **Python 3.12** и **ffmpeg**, если их нет (через winget);
- создаст виртуальное окружение **`biba_venv`** и поставит все пакеты
  из `requirements.txt`;
- спросит IP камеры (можно пропустить — потом ввести на странице);
- создаст `run.cmd` и ярлыки **«BIBA Eye»** с иконкой на рабочем столе и в меню Пуск.

## Запуск
- Ярлык **BIBA Eye** на рабочем столе / в меню Пуск, или
- `tools\biba_eye\run.cmd`, или вручную:
```powershell
tools\biba_eye\biba_venv\Scripts\python.exe tools\biba_eye\server.py
```
Страница откроется сама: **http://127.0.0.1:8081/**

## Настройки
Файл `tools/biba_eye/config.json` (создаётся автоматически):
```json
{
  "camera_ip": "192.168.1.107",
  "camera_user": "admin",
  "camera_pass": "888888",
  "rtsp_port": 554,
  "onvif_port": 8899,
  "profile": "balanced",
  "web_port": 8081,
  "ptz_speed": 0.5,
  "flip_x": 0,
  "flip_y": 0
}
```
- `profile`: `ultra` | `fast` | `balanced` | `quality`
- `ptz_speed`: скорость поворота (0.1–1.0)
- `flip_x` / `flip_y`: инверсия осей, если направления перепутаны
- Переменные окружения-переопределения: `BIBA_CAM_IP`, `BIBA_CAM_PASS`, `BIBA_WEB_PORT`

## API
- `GET /stream` — MJPEG-поток
- `GET /api/config` — конфигурация
- `POST /api/config` — сохранить IP/пароль (с проверкой ONVIF)
- `GET /api/discover` — скан подсети, поиск камер (порты 8899/554 + ONVIF)
- `POST /api/profile` — сменить профиль качества
- `POST /api/ptz` — `{"action":"up|down|left|right|stop"}`
- `GET /api/status` — состояние потока

## Требования
Устанавливаются автоматически `setup.ps1`:
- Python 3.8+ (winget `Python.Python.3.12`)
- ffmpeg (winget `Gyan.FFmpeg`)
- виртуальное окружение `biba_venv` + пакеты из `requirements.txt`
  (сам сервер использует только стандартную библиотеку)
- камера с включённым RTSP/ONVIF (V380 Pro → настройки камеры)

## Файлы
- `server.py` — сервер (видео + PTZ + поиск)
- `index.html` — страница оператора
- `setup.ps1` — установка одной строкой (Python/ffmpeg/venv/ярлыки)
- `requirements.txt` — пакеты для venv (сейчас пусто: сервер на stdlib)
- `biba_eye.ico` — иконка «глаз BIBA» для ярлыков
- `run.cmd` — запуск через `biba_venv` (создаётся setup.ps1)
- `biba_venv/` — виртуальное окружение BIBA (создаётся setup.ps1)
- `config.json` — настройки (создаётся при первом подключении)

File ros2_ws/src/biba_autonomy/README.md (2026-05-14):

# biba_autonomy (hook-point)

> SLAM, Nav2, waypoints, mission scripting. Пустая директория с `COLCON_IGNORE`.

Целевая роль: локальная автономия композиции C. Конкретный SLAM-стек (rtabmap vs cartographer vs Nav2-only) выбирается отдельным design-doc'ом. Требует Pi 4/5 и LiDAR.

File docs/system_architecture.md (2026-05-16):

# Системная архитектура BiBa

Этот документ — канонический обзор всех трёх аппаратных композиций робота, ответственности SBC и STM32, профилей ROS2-стека и точек расширения. Он рассчитан на тех, кто открывает репозиторий впервые и хочет за один проход понять «что где живёт». Низкоуровневая часть STM32 описана в [stm32_architecture.md](stm32_architecture.md), будущий ROS2-стек — в [ros2_stack.md](ros2_stack.md), развёртывание — в [deployment.md](deployment.md), а каноническая матрица готовности платформ — в [variants.md](variants.md). Исходный design-doc, из которого выведен этот текст, — [plans/2026-04-28-sbc-architecture-redesign-design.md](plans/2026-04-28-sbc-architecture-redesign-design.md).

## Контекст

Текущее состояние проекта:

- `biba-controller/` — Python-runtime, который умеет всё: CRSF UART, mixer, ramping, current-control, BTS7960 PWM, BMS, voice, web. Работает в одном compose-стеке (`docker/legacy-pi/docker-compose.yml`).
- `firmware/` — PlatformIO-проект для STM32F103 с режимами `standalone` / `companion` / `combined`. Прошивка может работать самостоятельно (CRSF → PWM → BTS7960) или быть SPI-slave'ом для SBC.
- `biba-controller/stm32_link/` — Python-каркас SPI-клиента к STM32, включается флагом `STM32_LINK_ENABLED=1`.

Новые входные требования, которые должна допускать архитектура (но необязательно реализовывать в этой итерации): манипулятор, ROS2, управление через интернет, внешние сенсоры (LiDAR, ToF, IMU), камера и FPV-stream, локальная автономия (SLAM, waypoints), UWB-модуль (BU4) для follow-the-tag, mission scripting.

## Три композиции робота

Проект поддерживает три аппаратные композиции одновременно. Это не три разных продукта, а три совместимых конфигурации одного и того же репозитория.

| Композиция | Железо | Кто читает CRSF | Кто крутит PWM | High-level стек |
| --- | --- | --- | --- | --- |
| **A. Pi-only** | Pi Zero 2W | Pi (UART) | Pi (BTS7960) | сегодняшний `biba-controller/` |
| **B. STM32-only** | STM32F103, без SBC | STM32 (USART3)  | STM32 | нет |
| **C. Pi + STM32** | SBC + STM32F103 | STM32 (USART3)  | STM32 | новый ROS2-стек |

Правило маршрутизации CRSF (зафиксировано): **где есть STM32, туда и идёт CRSF UART.** SBC получает каналы / RSSI / LQ / failsafe-флаг только через SPI-телеметрию от STM32. Pi-only композиция читает CRSF сама — как сегодня.

Композиция C на Pi Zero 2W поддерживается только в профиле minimal (см. ниже). Для тяжёлых узлов (SLAM, видео, WebRTC, ML) требуется Pi 4/5 или Orange Pi/Radxa — это явно фиксируется в документации развёртывания.

## Принципиальное архитектурное решение

Не превращать существующий `biba-controller/` в ROS2-стек и не ломать композицию A. Вместо этого ввести **второй высокоуровневый стек** для композиции C, основанный на ROS2, и держать оба стека в репозитории рядом друг с другом.

Причины:

- Композиция A работает и проверена на реальном железе. Любая переделка `biba-controller/` под ROS2 — это риск регрессии без компенсирующей пользы для тех, у кого STM32 нет.
- Pi Zero 2W (1 ГБ RAM, 4×Cortex-A53) тянет ROS2 + voice + web с трудом. Делать ROS2 единственным путём — значит резать Zero 2W.
- ROS2 даёт стандартные интерфейсы (`/cmd_vel`, `/odom`, `/battery_state`, `/joint_states`, TF, URDF) — это ровно то, во что естественно ложатся все новые направления (Nav2, манипулятор, UWB-follower, internet-bridge, ML, Foxglove).
- В композиции C тяжёлая низкоуровневая работа уже снята с SBC и живёт на STM32, поэтому SBC-сторона естественно становится «оркестратором узлов», а ROS2 — это и есть оркестратор узлов.

## Целевая структура репозитория

```
biba/
├── biba-controller/        # композиция A: Python-runtime, как сейчас
├── firmware/               # композиции B и C: STM32F103 PlatformIO
├── docker/
│   ├── base/               # общие base-образы (ROS2+Zenoh, ros2_control)
│   ├── legacy-pi/          # композиция A: docker-compose.yml + .env
│   └── ros2/               # композиция C: ROS2 docker-compose + сервисы
├── ros2_ws/
│   └── src/
│       ├── biba_description/        # URDF/xacro дифф-привода BiBa
│       ├── biba_msgs/               # кастомные сообщения (BMS, CRSF, motor-audio)
│       ├── biba_stm32_bridge/       # SPI ↔ ROS2 (Python, реюз stm32_link)
│       ├── biba_hardware_stm32/     # ros2_control SystemInterface (C++)
│       ├── biba_bringup/            # launch + конфиги controller_manager
│       └── (hook-points)            # пустые директории-плейсхолдеры:
│           biba_manipulator/        #   будущий пакет манипулятора
│           biba_uwb_follow/         #   follow-the-tag через BU4
│           biba_remote_bridge/      #   Zenoh / WebRTC / VPN bridge
│           biba_camera/             #   FPV stream и ML inference
│           biba_autonomy/           #   SLAM / Nav2 / waypoints / mission
├── docs/
│   ├── system_architecture.md      # этот файл
│   ├── stm32_architecture.md       # детали STM32-стороны
│   ├── ros2_stack.md               # пакеты, топики, launch
│   ├── deployment.md               # дополнен per-композиция
│   └── wiring.md                   # отметки по пинам каждой композиции
└── README.md                       # архитектурный hub
```

## ROS2-стек: контейнеры и узлы

Шаблон контейнеризации копируется с проекта `rob_box_project`:

- Один контейнер на ROS2-узел (или тесно связанную группу).
- Zenoh router (`eclipse/zenoh`) как RMW-транспорт; ROS2 поверх `rmw_zenoh_cpp`. Это даёт естественный мост в облако и в internet-bridge.
- Базовые образы строятся отдельно (`docker/base/Dockerfile.ros2-zenoh`, `Dockerfile.ros2-control` и т.д.), сервисные — поверх них. Образы публикуются в GHCR с тегом `<service>-<distro>-<branch>`.

Состав композиции C, профиль **minimal** (доступен и на Pi Zero 2W при ужатой воле):

| Контейнер | Узел / роль |
| --- | --- |
| `zenoh-router` | Zenoh маршрутизация + точка для облачного bridge |
| `robot-state-publisher`| URDF → TF из `biba_description` |
| `biba-stm32-bridge` | `biba_stm32_bridge`: SPI ↔ топики (`/cmd_vel`, `/joint_states`, `/battery_state`, `/crsf/status`, `/motor_audio`) |
| `ros2-control` | controller_manager + `diff_drive_controller` + `joint_state_broadcaster`; hardware interface = `biba_hardware_stm32` |
| `twist-mux` | приоритизация источников `cmd_vel`: CRSF → manual → autonomy |

Профиль **full** (Pi 4/5+) добавляет опционально:

| Контейнер | Источник |
| --- | --- |
| `biba-camera` | `biba_camera`: FPV-stream, опционально ML inference |
| `biba-autonomy` | `biba_autonomy`: SLAM (rtabmap/cartographer) и/или Nav2 |
| `biba-manipulator` | `biba_manipulator`: ros2_control hardware для servo-контроллера |
| `biba-uwb-follow` | `biba_uwb_follow`: BU4 → tag pose → `cmd_vel` |
| `biba-remote-bridge` | `biba_remote_bridge`: Zenoh-bridge / MQTT / WebRTC outward |
| `foxglove-bridge` | штатный `foxglove_bridge` для удалённой диагностики |

Профили реализуются через docker-compose `profiles:` или через override-файлы — выбор делается на этапе реализации.

## Контракт `biba_stm32_bridge` ↔ STM32

Узел `biba_stm32_bridge` — единственный, кто разговаривает с STM32 по SPI. Он повторно использует `biba-controller/stm32_link/protocol.py` и `stm32_link/client.py` без копирования.

Публикуемые ROS2-топики (предварительный список, доточить в реализации):

| Топик | Тип сообщения | Источник |
| --- | --- | --- |
| `/joint_states` | `sensor_msgs/JointState` | echo setpoint + measured currents |
| `/battery_state` | `sensor_msgs/BatteryState` | агрегация из BMS и из STM32 telemetry rail |
| `/imu/data_raw` | `sensor_msgs/Imu` | gyro/accel из STM32 telemetry |
| `/biba/crsf/status` | `biba_msgs/CrsfStatus` | RSSI/LQ/SNR/failsafe-flag |
| `/biba/stm32/telemetry` | `biba_msgs/Stm32Telemetry` | сырая SPI-snapshot для диагностики |

Подписки (входы):

| Топик | Тип | Действие |
| --- | --- | --- |
| `/cmd_vel` | `geometry_msgs/Twist` | → `SET_SETPOINT` (через mixer) |
| `/biba/arm` (service) | `std_srvs/SetBool` | → `ARM` / `DISARM` |
| `/biba/motor_audio` | `biba_msgs/MotorAudio` | → `SET_MOTOR_AUDIO` (если target умеет) |

Mixer twist→left/right остаётся в `biba_stm32_bridge` (или в controller-side через `diff_drive_controller`, окончательное решение в плане реализации).

## High-level задачи SBC по композициям

### A. Pi-only

Сегодняшний набор без изменений: CRSF, mixer, ramping, current-control, BTS7960 PWM, BMS-poller, voice, web, system-stats. Новые направления (ROS2/манипулятор/UWB/интернет) в этой композиции **не поддерживаются** — для них нужно перейти на композицию C.

### B. STM32-only

SBC отсутствует. Высокоуровневых задач нет вообще. Это минимальная сборка для людей без Pi: только драйв, телеметрия по CRSF обратно оператору, motor-audio.

### C. Pi+STM32

Низкоуровневая часть полностью на STM32. На SBC — только high-level:

1. **Drive-bridge** — `biba_stm32_bridge` + `ros2_control`. MUST.
2. **Robot description** — URDF/TF через `robot_state_publisher`. MUST.
3. **Twist arbitration** — `twist_mux` с приоритетами CRSF > teleop > autonomy. MUST.
4. **BMS aggregation** — отдельный узел или часть bridge'а, публикует `/battery_state`. MUST (или MAY, если на STM32-target есть VBAT-sense и хватает её).
5. **Telemetry-out** — Zenoh router; внешний `foxglove_bridge` опционально.
6. **Voice runtime** — переезд из `biba-controller/buzzer/voice` в отдельный ROS2-узел `biba_voice` (вне scope этого документа). На время миграции допустимо запускать `biba-controller` рядом с ROS2-стеком на одной Pi для voice.
7. **Web UI** — то же: остаётся в `biba-controller` до отдельной миграции.

Расширения (отдельные планы, отдельные дизайны):

- Манипулятор: `biba_manipulator` как `ros2_control` системой поверх USB/I2C servo-контроллера. Топики `/manipulator/joint_states` и `/manipulator/joint_trajectory_controller/...`.
- Internet remote control: `biba_remote_bridge` через Zenoh→облачный Zenoh-router и/или WebRTC для видео.
- Камера и ML: `biba_camera`, отдельный контейнер, требует Pi 4/5.
- Автономия: `biba_autonomy` (rtabmap или Nav2), требует Pi 4/5 и LiDAR.
- UWB-follower: `biba_uwb_follow`, отдельный контейнер; читает BU4 по USB/UART, публикует pose тага и/или прямо `cmd_vel` с низким приоритетом в `twist_mux`.
- Mission scripting: `biba_autonomy` или отдельный пакет; использует ROS2 actions поверх `nav_to_pose` и пользовательских действий.

## Failsafe и приоритеты команд (композиция C)

- **Independent failsafe (STM32):** STM32 отвечает за немедленный cut-off моторов при потере CRSF и при истечении SPI watchdog (`SPI_LINK_TIMEOUT_MS`). SBC может упасть полностью — это допустимо.
- **Twist arbitration (SBC):** `twist_mux` строит приоритетную лестницу, но это уже вторичный уровень. Манипулятор работает в своей цепи `ros2_control` и не пересекается с drive twist'ом.
- **Arm/Disarm:** owner — STM32 (по CRSF-каналам). SBC может только запросить disarm (`/biba/arm` service → `DISARM` cmd), но не может принудительно армить, если CRSF в failsafe.

## Куда смотреть дальше

- [stm32_architecture.md](stm32_architecture.md) — STM32-сторона: SPI-протокол, режимы прошивки, контракт телеметрии.
- [ros2_stack.md](ros2_stack.md) — ROS2-стек композиции C: пакеты, контейнеры, топики.
- [deployment.md](deployment.md) — развёртывание per-композиция.
- [wiring.md](wiring.md) — пины и подключение.
- [plans/2026-04-28-sbc-architecture-redesign-design.md](plans/2026-04-28-sbc-architecture-redesign-design.md) — исходный design-doc с историей решений и списком эпиков.

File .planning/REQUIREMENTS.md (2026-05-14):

# Requirements: BiBa

**Defined:** 2026-05-14
**Core Value:** Робот должен ехать и слушаться пульта в любых условиях — всё остальное вторично.

## v1 Requirements

Requirements for RP2040 port milestone. Each maps to roadmap phases.

### CRSF / Radio Control

- [ ] **CRSF-01**: RP2040 принимает ELRS/CRSF пакеты по UART и декодирует каналы управления
- [ ] **CRSF-02**: Потеря CRSF-сигнала определяется в течение ≤500 мс и активирует failsafe (стоп моторов)
- [ ] **CRSF-03**: Каналы управления корректно маппируются на команды привода (дифференциальный микс)

### Motor Control

- [ ] **MOTOR-01**: RP2040 управляет двумя каналами BTS7960 (левый/правый) через hardware PWM
- [ ] **MOTOR-02**: При старте все motor-enable пины LOW до получения первой валидной CRSF-команды
- [ ] **MOTOR-03**: Плавный разгон/торможение (ramping) реализован для защиты передачи и BTS7960

### Arming & Failsafe

- [ ] **SAFE-01**: Арминг/разарм через dedicated switch на пульте работает корректно
- [ ] **SAFE-02**: После потери связи или disarm — моторы останавливаются, не зависают в состоянии
- [ ] **SAFE-03**: Deadband по нейтральному положению стиков исключает ложные движения

### IMU Stabilization

- [ ] **IMU-01**: IMU (BMI160 или LSM6DS3) инициализируется на RP2040 по I2C/SPI
- [ ] **IMU-02**: Heading-hold режим (удержание курса по гироскопу) работает на RP2040
- [ ] **IMU-03**: Gyro bias калибруется при старте (стоп > 2 сек = калибровка)
- [ ] **IMU-04**: Оси гироскопа корректно маппированы для BiBa (yaw → дифференциал колёс)

### Current Sensing

- [ ] **CURR-01**: Замеры тока с BTS7960 IS-пинов (или ADS1115) работают на RP2040
- [ ] **CURR-02**: Перегрузка по току вызывает software throttle (не жёсткий стоп)
- [ ] **CURR-03**: Показания тока логируются через UART/USB для отладки

### Trim

- [ ] **TRIM-01**: Триминг каналов (дрейф нейтрали) настраивается и сохраняется в flash
- [ ] **TRIM-02**: Сохранённые трим-значения восстанавливаются при перезагрузке

### Thermal Protection

- [ ] **THERM-01**: Программная защита: при превышении тока/температуры применяется throttle back
- [ ] **THERM-02**: Аппаратная теплоотводящая пластина под BTS7960 установлена (hardware task)

### Hardware Variant Matrix

- [ ] **VARIANT-01**: Документирована таблица вариантов: плата × тип мотора × тип драйвера × опциональные модули
- [ ] **VARIANT-02**: Каждый вариант имеет статус (ready / WIP / planned) и ссылку на target.md или ветку

## v2 Requirements

Deferred to future release. Tracked but not in current roadmap.

### BiBa Extended (Post-RP2040 Phase)

- **VOICE-01**: Голосовые ассеты и звуковая индикация на RP2040
- **BMS-01**: Daly BMS интеграция (BLE/UART) на RP2040
- **LED-01**: LED-матрицы (WS2812 фары/индикаторы) управляются с RP2040
- **TELEM-01**: CRSF обратная телеметрия (VBAT, ток) на пульт
- **COMP-01**: Companion mode — RP2040 как SPI-слейв для Pi Zero 2W

### ROS2 / Autonomous

- **ROS2-01**: BiBa ноды в ROS2 workspace на Pi Zero 2W
- **NAV-01**: Follow-me режим (следование за меткой)

## Out of Scope

Explicitly excluded from RP2040 port milestone.

| Feature | Reason |
|---|---|
| Web UI / browser telemetry | Только пульт — no network stack on RP2040 в Phase 1 |
| BMS integration (RP2040) | Python/BLE сложность, откладывается на Pi Zero 2W ветку |
| Voice assets (RP2040) | Нет достаточного RAM на Pico для audio processing |
| ODrive/VESC support (code) | Документируется в матрице, не реализуется в этой фазе |
| Follow-me / autonomous nav | За пределами RC управления |
| ROS2 integration | Отдельный milestone для Pi Zero 2W |
| Docker stack on RP2040 | Нет Linux, не применимо |

## Traceability

Which phases cover which requirements. Updated during roadmap creation.

| Requirement | Phase | Status |
|---|---|---|
| CRSF-01 | Phase 1 | Pending |
| CRSF-02 | Phase 1 | Pending |
| CRSF-03 | Phase 1 | Pending |
| MOTOR-01 | Phase 1 | Pending |
| MOTOR-02 | Phase 1 | Pending |
| MOTOR-03 | Phase 1 | Pending |
| SAFE-01 | Phase 1 | Pending |
| SAFE-02 | Phase 1 | Pending |
| SAFE-03 | Phase 1 | Pending |
| IMU-01 | Phase 2 | Pending |
| IMU-02 | Phase 2 | Pending |
| IMU-03 | Phase 2 | Pending |
| IMU-04 | Phase 2 | Pending |
| CURR-01 | Phase 2 | Pending |
| CURR-02 | Phase 2 | Pending |
| CURR-03 | Phase 2 | Pending |
| TRIM-01 | Phase 2 | Pending |
| TRIM-02 | Phase 2 | Pending |
| THERM-01 | Phase 3 | Pending |
| THERM-02 | Phase 3 | Pending |
| VARIANT-01 | Phase 3 | Pending |
| VARIANT-02 | Phase 3 | Pending |

**Coverage:**
- v1 requirements: 22 total
- Mapped to phases: 22
- Unmapped: 0 ✓

---
*Requirements defined: 2026-05-14*
*Last updated: 2026-05-14 after initialization*

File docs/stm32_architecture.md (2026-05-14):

# STM32F103 firmware architecture

Этот документ описывает firmware-проект `firmware/` для STM32F103C8T6
("Blue Pill") — опционального добавочного микроконтроллера к BiBa,
который умеет работать либо самостоятельно, либо как SPI-slave к основному
одноплатному компьютеру (Pi Zero 2W / Pi 5 / аналог).

> Этот документ описывает только STM32-сторону. Общую картину трёх композиций
> робота и роль STM32 в каждой смотрите в [system_architecture.md](system_architecture.md).
> Соответствие режимов прошивки и композиций:
>
> - **Standalone** — композиция B (STM32-only, без SBC).
> - **Companion** — композиция C (Pi + STM32, ROS2-стек на SBC).
> - **Combined** — отладочный гибрид; в продакшене не используется.

## Зачем это нужно

1. Забрать у Pi hard-realtime задачи: CRSF на 420 000 бод с DMA, PWM для
   двух BTS7960 с dead-time, быстрый current-sense через штатный ADC.
2. Сохранить весь «умный» runtime на Linux: voice, web, телеметрия в
   сторону оператора, autonomy.
3. Дать возможность построить «urto-minimal» биобота без SBC — только
   STM32 + приёмник + два BTS7960.

## Два режима работы

> Соответствие композициям робота: **Standalone = композиция B**, **Companion = композиция C**. См. [system_architecture.md](system_architecture.md#три-композиции-робота).

### Standalone (композиция B)

Весь низкоуровневый стек живёт на STM32:

```
CRSF UART ──▶ парсер ──▶ mixer ──▶ heading-hold PID ──▶ limiter ──▶ PWM → BTS7960
                                                             ▲
                                      ADC1 circular DMA ─────┘
```

Pi (если вообще есть) подключается по желанию через SPI для сбора
телеметрии или как источник high-level команд.

### Companion (композиция C)

SBC — владелец setpoint-а; STM32 — "умный драйвер", который:

- принимает команды по SPI-slave,
- следит за current / power лимитами своим ADC,
- возвращает полную телеметрию на MISO,
- уходит в фейлсейф, если SPI молчит дольше `SPI_LINK_TIMEOUT_MS`.

CRSF опционально активен как локальный override / независимый
фейлсейф-канал.

### Combined

Единая прошивка, режим выбирается при старте по пину `MODE_SEL`
(`pull-up`; замыкание на GND = companion). Сам пин зависит от
выбранного target'а: на `BLUEPILL_F103C8` это PB9, на `BIBA_F103_REV_A`
и его клоне живёт PA7 (PB9 там занят под TIM4_CH4). Это позволяет
одной прошивкой закрывать обе сборки робота.

## Targets (Betaflight/ELRS-style)

Конкретная привязка пинов и per-board калибровка отделены от портируемой
логики — ровно как в Betaflight и ExpressLRS. Каждая аппаратная
конфигурация живёт в `firmware/targets/<TARGET>/`:

```
targets/<TARGET>/
├── target.h            # pin map + BIBA_TARGET_HAS_* feature flags
├── target_config.h     # per-board калибровка / лимиты
└── target.md           # документация борды
```

Портируемый код включает только `biba_board.h` и `biba_config.h` —
это тонкие shim'ы, которые через путь `-Itargets/<TARGET>` (инжектится
PlatformIO per-env) подтягивают `target.h` и `target_config.h` выбранной
борды. Никаких `#ifdef TARGET == …` в `src/`.

Каждая hardware-конфигурация собирается в комбинации с каждым режимом
(`<target>_<mode>`), давая матрицу сборки `T × M`. Сейчас
поставляются:

| Target | Плата |
| --- | --- |
| `BLUEPILL_F103C8` | Стоковая "Blue Pill" с настоящим чипом (20 КБ ОЗУ) |
| `BLUEPILL_F103C8_CLONE` | Та же распиновка, но клон-чип с 8 КБ ОЗУ |
| `BIBA_F103_REV_A` | Пример кастомного PCB (прототип Rev A) |

Вариант `_CLONE` не имеет своей директории в `targets/` — он
переиспользует `BLUEPILL_F103C8/target.h` буква в букву и
отличается лишь линкер-скриптом (`firmware/ldscripts/stm32f103_8k_ram.ld`,
`LENGTH(RAM) = 8K`) и лимитом RAM в PlatformIO. Стоковый CMSIS-линкер
кладёт `_estack` на `0x20005000`, что на клоне выходит за пределы
реального ОЗУ и роняет MCU в HardFault на первом же прерывании.

Добавление нового target'а = одна новая директория + один `[target_*]`
блок в `platformio.ini`, без правок портируемого кода. Подробнее — в
[`firmware/targets/README.md`](../firmware/targets/README.md).

## Слои прошивки

```
┌──────────────────────────────────────────────────────────┐
│ modes/        mode_dispatcher.c, mode_{standalone,companion}.c │
├──────────────────────────────────────────────────────────┤
│ app/          control_loop (mixer, PID, limiter),        │
│               failsafe, telemetry                        │
├──────────────────────────────────────────────────────────┤
│ drivers/      bts7960, current_sense, voltage_sense,     │
│               crsf, imu                                  │
├──────────────────────────────────────────────────────────┤
│ hal/          biba_hal: clock, GPIO, motor PWM, ADC+DMA, │
│               USART3+DMA, SPI2-slave+DMA, I2C1           │
├──────────────────────────────────────────────────────────┤
│ proto/        biba_proto.{h,c} — общий SPI wire format   │
└──────────────────────────────────────────────────────────┘
```

Слои `proto`, `app/control_loop`, `app/failsafe`, `drivers/crsf` — чистый
переносимый C. Они компилируются под хост в env `native_test` и имеют
Unity-тесты (`test/test_biba_proto/`, `test/test_control_loop/`,
`test/test_crsf/`), которые CI гоняет на каждый push.

Всё, что трогает регистры STM32, лежит в `hal/biba_hal.c` (плюс
`hal/biba_hal_motor.c` для мотор-PWM и motor-audio, и
`hal/biba_hal_debug.c` для семихостинг-логирования при отладке) и
исключается из native-сборки через `build_src_filter` в
`platformio.ini`.

## Распиновка

См. таблицу в [docs/wiring.md](wiring.md#подключение-stm32f103). Короткая
сводка привязок:

- **Motor PWM** — распиновка зависит от target'а:
  - `BLUEPILL_F103C8`: все 4 канала на **TIM1** (PA8..PA11), общий
    несущий carrier ⇒ один набор частот для всех 4 линий.
  - `BIBA_F103_REV_A`: каждая из 4 линий висит на **своём таймере**
    (TIM1/TIM2/TIM3/TIM4). В тяговом режиме HAL держит одинаковый ARR
    на всех, в audio-режиме ARR/PSC/CCR программируются независимо —
    это и есть motor-audio через BTS7960 (у BiBa нет buzzer'а).
    Флаг target'а: `BIBA_TARGET_HAS_PER_CHANNEL_TIMER_PWM`.
- **ADC1** — circular DMA-скан PA0..PA6 (4 current + 2 voltage + 1
  резерв), 12 бит, 55.5 циклов sample time.
- **USART3** — CRSF на PB10/PB11, 420 000 бод, DMA1 Channel 3.
- **SPI2** — slave-линия к SBC на PB12..PB15, NSS hardware, DMA1 Ch4/Ch5.
- **I2C1** — IMU на PB6/PB7, 400 кГц.
- **SWJ** — JTAG отключается в `biba_hal_init()`, остаётся SW-DP;
  PB3/PB4/PA15 освобождаются под GPIO / enable-пины BTS7960.

USART1 намеренно не используется: его AF-пины PA9/PA10 занимают TIM1_CH2
и TIM1_CH3 для PWM.

## SPI wire protocol

Full-duplex обмен, каждая SPI-транзакция передаёт один 64-байтный кадр в
каждую сторону. STM32 всегда держит на MISO свежий telemetry snapshot,
поэтому у SBC нет необходимости делать отдельный "запрос телеметрии".

Раскладка кадра (64 байта):

| offset | size | field | комментарий |
|---:|-----:|---|---|
| 0 | 2 | sync | `0xBA 0xBB` |
| 2 | 1 | version | `0x01` (константа `BIBA_PROTO_VERSION`) |
| 3 | 1 | cmd | `biba_proto_cmd_t` / `biba_proto_tlm_t` |
| 4 | 1 | seq | монотонный счётчик отправителя |
| 5 | 1 | flags | `BIBA_PROTO_FLAG_*` |
| 6 | 1 | payload_len | 0..54 |
| 7 | 1 | reserved | должен быть 0 |
| 8–61 | 54 | payload | команд-специфично |
| 62 | 2 | crc16 | CRC-16/CCITT-FALSE по байтам 0..61 |

CRC — `CRC-16/CCITT-FALSE` (poly 0x1021, init 0xFFFF, no reflect, xorout 0).
Та же реализация живёт в Python в
[`biba-controller/stm32_link/protocol.py`](../biba-controller/stm32_link/protocol.py)
и оба имплементатора покрыты тестами с одинаковыми vector-ами.

### Основные команды (SBC → STM32)

| cmd  | имя | payload |
|:----:|---|---|
| 0x01 | `PING` | пустой |
| 0x10 | `SET_SETPOINT` | `int16 left_q15, int16 right_q15` |
| 0x11 | `GET_TELEMETRY`  | пустой |
| 0x20 | `ARM` | пустой |
| 0x21 | `DISARM` | пустой |
| 0x30 | `SET_CONFIG` | TLV (резерв) |
| 0x40 | `SET_MOTOR_AUDIO`| `uint16 freq_hz[4]; uint8 duty_q8[4]; uint8 flags` |

`SET_MOTOR_AUDIO` адресует 4 канала PWM (L_RPWM, L_LPWM, R_RPWM,
R_LPWM) и применим только к target'ам с
`BIBA_TARGET_HAS_PER_CHANNEL_TIMER_PWM == 1` — на остальных firmware
молча игнорирует команду. Звука через buzzer у BiBa нет: тон даётся
напрямую через ключи BTS7960.

### Телеметрия (STM32 → SBC)

`cmd = 0x82` (SNAPSHOT). Payload — упакованная структура
`biba_proto_telemetry_t` (48 байт): setpoint echo, измеренные токи в мА,
VBAT, 12V rail, gyro/accel в centi-deg/s и milli-g, CRSF RSSI/LQ/SNR,
флаги и uptime в миллисекундах.

### DATA_READY (PA12)

STM32 поднимает PA12 коротким импульсом после каждого нового ADC-скана.
SBC может навесить на этот пин GPIO-interrupt и опрашивать телеметрию
реактивно, без фиксированного 1 кГц polling.

### Failsafe

- **Companion**: если SPI молчит дольше `BIBA_SPI_LINK_TIMEOUT_MS`,
  PWM обнуляется, BTS7960 дизабл, флаг `BIBA_PROTO_FLAG_FAILSAFE`
  выставляется в каждой телеметрии.
- **Standalone**: если CRSF молчит дольше `BIBA_CRSF_TIMEOUT_MS`, PWM
  обнуляется, PID-интегратор сбрасывается.

## Интеграция с Pi-runtime

Python-клиент живёт в [`biba-controller/stm32_link/`](../biba-controller/stm32_link/):

- `protocol.py` — энкодинг/декодинг фреймов (без `spidev`, 100% портируемо).
- `client.py` — `STM32Link` — SPI-мастер поверх `spidev`.
- По умолчанию отключён через `STM32_LINK_ENABLED=0` в `config.py`, так
  что существующий GPIO-путь не трогается.

## Дерево файлов

```
firmware/
├── platformio.ini           # matrix: <target>_<mode>, плюс native_test
├── ldscripts/               # кастомные линкер-скрипты (например, 8 КБ ОЗУ для клона)
├── include/                 # thin shims -> targets/<TARGET>/target*.h
├── src/
│   ├── main.c
│   ├── proto/biba_proto.*   # общий SPI wire format
│   ├── app/                 # control_loop, failsafe, telemetry
│   ├── drivers/             # bts7960, current/voltage_sense, crsf, imu
│   ├── hal/biba_hal.*       # STM32Cube wrapper (+ biba_hal_motor.c, biba_hal_debug.c)
│   └── modes/               # диспетчер + standalone / companion
├── targets/
│   ├── README.md            # how to add a new target
│   ├── BLUEPILL_F103C8/     # reference Blue Pill pinout
│   └── BIBA_F103_REV_A/     # пример кастомной PCB
└── test/
    ├── test_biba_proto/     # CRC16 + frame round-trip
    ├── test_control_loop/   # PID, лимитер, mixer, failsafe
    ├── test_crsf/           # CRC8, парсер, канальная упаковка
    └── test_support/        # общий shim для native / Unity (+ unity_config.h)
```

## Валидация

- **Host-side**: `pio test -e native_test` — 31 тест на CRC, парсер CRSF,
  парсер SPI-кадров, лимитер по току/мощности, PID anti-windup.
- **Сборочные env**: `pio run -e <target>_<mode>` для каждой пары
  `target × mode`. Все пары собираются в CI
  (`.github/workflows/G-Build-STM32F103.yml`), артефакт
  `biba-stm32f103-<target>-<mode>` (`firmware.bin` + `.elf`) прикрепляется
  к workflow run.
- **На железе**: ST-Link + `pio run -e <target>_<mode> -t upload`, далее
  сверка с Pi-реф behaviour (CRSF RSSI, PWM на осциллографе, current-sense
  против ADS1115).

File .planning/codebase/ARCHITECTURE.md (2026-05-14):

---
doc: ARCHITECTURE
last_mapped: 2026-05-14
---

# Architecture

## Pattern

**Dual-stack embedded platform with optional ROS2 overlay.**

BiBa supports three hardware compositions managed from the same repository:

- **Composition A (Pi-only):** Raspberry Pi Zero 2W runs the full Python runtime in `biba-controller/`. Pi reads CRSF over UART, mixes, ramps, and directly drives BTS7960 H-bridges via GPIO/pigpio.
- **Composition B (STM32-only):** STM32F103 operates standalone — reads CRSF, drives PWM, provides telemetry. No SBC.
- **Composition C (Pi + STM32):** STM32 handles all low-level CRSF/PWM/current-limiting. Pi runs a ROS2 stack (`ros2_ws/`) and sends setpoints via SPI. This is the path for Nav2, SLAM, manipulation, and internet bridging.

The key architectural rule: **wherever STM32 is present, it owns CRSF UART.** The SBC receives channel values and RSSI only through SPI telemetry from the STM32. Pi-only composition reads CRSF itself.

---

## Layers / Components

### Composition A — Python Runtime (`biba-controller/`)

```
┌─────────────────────────────────────────────────────────────────┐
│            Entry Point: biba-controller/main.py                  │
│   ~20 Hz control loop: read CRSF → mix → ramp → limit → drive   │
├──────────────┬──────────────┬───────────────┬───────────────────┤
│  CRSF Layer  │  Motor Layer │  Sensor Layer │  Audio Layer      │
│  crsf/       │  motors/     │  bms/, imu/   │  buzzer/, voice/  │
├──────────────┴──────────────┴───────────────┴───────────────────┤
│              Configuration: config.py (env-var driven)           │
│              Persistence: settings_store.py, pid_tuning.py       │
├──────────────────────────────────────────────────────────────────┤
│      Web / Debug API: motor_test_api.py + web/                   │
│      (stdlib ThreadingHTTPServer on MOTOR_TEST_API_PORT)         │
├──────────────────────────────────────────────────────────────────┤
│   STM32 SPI Link (optional): stm32_link/  [STM32_LINK_ENABLED=1] │
└──────────────────────────────────────────────────────────────────┘
         │ pigpio GPIO/PWM          │ UART (serial)
         ▼                          ▼
   BTS7960 H-bridges            CRSF receiver / ExpressLRS TX
```

### Composition C — ROS2 Stack (`ros2_ws/`)

```
┌──────────────────────────────────────────────────────────────────┐
│  twist_mux  →  /cmd_vel  →  biba_stm32_bridge (Python ROS2 node) │
│                              ros2_ws/src/biba_stm32_bridge/       │
├──────────────────────────────────────────────────────────────────┤
│  biba_hardware_stm32 (C++ ros2_control SystemInterface)          │
│  ros2_ws/src/biba_hardware_stm32/                                │
├──────────────────────────────────────────────────────────────────┤
│  biba_stm32_bridge/stm32_link/  ←  reuses biba-controller code   │
└────────────────────────┬─────────────────────────────────────────┘
                         │ SPI (biba_proto)
                         ▼
              STM32F103 firmware/  (companion mode)
```

### Firmware (`firmware/`)

```
firmware/src/
├── main.c / main_rp2040.cpp     # MCU entry point, peripheral init
├── modes/
│   ├── mode_standalone.c        # CRSF → local PWM (no SBC)
│   ├── mode_companion.c         # SPI slave, SBC owns setpoints
│   └── mode_dispatcher.c        # selects mode at compile/runtime
├── app/
│   ├── control_loop.c/h         # current limiting, PID helpers
│   ├── failsafe.c/h             # SPI watchdog + CRSF watchdog
│   ├── telemetry.c/h            # builds SPI telemetry snapshots
│   └── melody.c/h               # buzzer melody engine
├── drivers/
│   ├── bts7960.c/h              # H-bridge PWM driver
│   ├── crsf.c/h                 # CRSF UART decoder
│   ├── current_sense.c/h        # ADC current sense
│   ├── imu.c/h                  # gyro/accel I2C
│   └── voltage_sense.c/h        # battery voltage ADC
├── hal/
│   ├── biba_hal.c/h             # hardware abstraction layer
│   ├── biba_hal_motor.c         # STM32F103 PWM output
│   └── biba_hal_motor_rp2040.c  # RP2040 PWM output
└── proto/
    ├── biba_proto.c/h           # SPI wire protocol (64-byte frames, CRC-16/CCITT)
```

---

## Entry Points

| Entry Point | Path | Description |
|---|---|---|
| Python runtime | `biba-controller/main.py` → `main()` at line 1298 | ~20 Hz control loop; initializes all subsystems, runs until SIGTERM |
| Firmware (STM32F103) | `firmware/src/main.c` | PlatformIO C entry; dispatches to standalone/companion mode |
| Firmware (RP2040) | `firmware/src/main_rp2040.cpp` | RP2040 variant |
| ROS2 bridge node | `ros2_ws/src/biba_stm32_bridge/biba_stm32_bridge/bridge_node.py` | `Stm32BridgeNode` — subscribes `/cmd_vel`, publishes telemetry |
| Voice audition mode | `biba-controller/main.py` → `_run_voice_audition_mode()` at line 505 | Activated by `VOICE_AUDITION_ENABLED=1` env var |
| Motor test web API | `biba-controller/motor_test_api.py` → `create_motor_test_server()` | stdlib `ThreadingHTTPServer`, runs in sidecar thread |

---

## Data Flow

### Composition A — Primary Control Loop (~20 Hz)

1. **CRSF read** — `CRSFReceiver.read_frame()` (`biba-controller/crsf/receiver.py`) reads serial bytes; returns 16 RC channels normalized to -1.0..1.0
2. **Arm/mode decode** — `main.py:_is_armed()`, `_get_drive_mode()`, `_get_speed_mode_scale()` interpret specific channels
3. **IMU-assisted drive** (optional) — `AssistedDriveController.compute()` (`motors/assisted_drive.py`) applies yaw-rate PID stabilization if drive mode ≠ MANUAL
4. **Throttle filter** — `ScalarKalmanFilter` (`motors/ramping.py`) smooths throttle input
5. **Mix + ramp** — `DifferentialDrive.mix_and_ramp()` (`motors/driver.py`) converts throttle/steering to left/right duty with speed ramps
6. **Motor trim** — `_apply_motor_trim()` in `main.py` adds saved trim offset
7. **Current limiting** — `apply_motor_limits()` (`motors/current_control.py`) reads ADS1115 ADC samples and scales down duty if current/power exceeded
8. **Drive output** — `DifferentialDrive.apply_output()` → `BTS7960MotorDriver.set_speed()` → pigpio PWM
9. **CRSF telemetry TX** — `CRSFTelemetry.send_battery()` + `send_system()` (`crsf/telemetry.py`) at `BMS_POLL_INTERVAL_S` cadence
10. **BMS** — `BMSPoller` runs in background thread; exposes `latest_state: Optional[BatteryState]` with a lock

### Composition A — STM32 SPI Path (opt-in, `STM32_LINK_ENABLED=1`)

1. `STM32Link.send_receive()` (`stm32_link/client.py`) performs full-duplex SPI exchange of 64-byte `biba_proto` frames
2. Pi sends `SET_SETPOINT` command with Q15 left/right duty; STM32 replies with `SNAPSHOT` telemetry
3. Protocol defined in `stm32_link/protocol.py` (Python) and `firmware/src/proto/biba_proto.h` (C) — kept byte-for-byte identical; CI drift test in `tests/test_biba_proto_drift.py`

### Composition C — ROS2 Control Flow

1. `twist_mux` (launch `ros2_ws/src/biba_bringup/launch/twist_mux.launch.py`) arbitrates competing `/cmd_vel` sources with priorities: CRSF > manual teleop > autonomy
2. `Stm32BridgeNode` subscribes `/cmd_vel`, converts `Twist` to differential setpoint via `translator.py`, sends `SET_SETPOINT` to STM32 via SPI at `setpoint_rate_hz` (default 50 Hz)
3. STM32 telemetry is read at `telemetry_rate_hz` (default 20 Hz) and published as `biba_msgs/Stm32Telemetry` and `biba_msgs/CrsfStatus`
4. `biba_hardware_stm32` implements `ros2_control` `SystemInterface` — exposes wheel joints to `diff_drive_controller`

### Audio / Voice

- **Synth mode:** `MotorSynth` (`buzzer/motor_synth.py`) generates motor-coil tones via hardware PWM pins (pigpio)
- **Voice mode:** `WavPlayer` (`buzzer/wav_player.py`) plays WAV files either as PCM-over-PWM (carrier modulation) or as spectral vocoder (STFT → dominant-frequency frame sequence)
- `VoiceSelector` (`buzzer/voice_selector.py`) implements round-robin selection across variant files for each event
- `BeaconManager` (`buzzer/beacon.py`) manages SOS/beacon state independent of main arm state

---

## Abstractions

### Null Object Pattern (Composition A)

`main.py` defines two null objects used when hardware is absent:

- `_NullDrive` — duck-type compatible with `DifferentialDrive`; all motor methods return `(0.0, 0.0)`. Used when motor driver init fails.
- `_NullBuzzer` — duck-type compatible with the full buzzer; all methods are no-ops. Used when `SOUND_MODE=none` or init fails.

Also from library code:
- `NullIMUReader` (`imu/__init__.py`) — returns stale zero samples
- `NullMotorCurrentReader` (`motors/current_sense.py`) — returns `valid=False` samples

### Protocol Codecs (biba_proto)

`stm32_link/protocol.py` is the canonical Python implementation of the SPI wire format. It mirrors `firmware/src/proto/biba_proto.h` field-for-field:
- 64-byte fixed frames: 8 byte header, up to 54 byte payload, 2 byte CRC-16/CCITT
- Sync bytes `0xBA 0xBB`, version, command/telemetry ID, sequence counter, flags bitfield

### Factory Functions

- `imu/factory.py:open_imu_reader()` — autodetects BMI160 vs LSM6DS3 by WHO_AM_I register; returns typed reader
- `motors/current_sense.py:open_ads1115_current_reader()` — creates configured ADS1115 reader
- `main.py:_create_buzzer()`, `_create_motor_pair()`, `_create_bms()` — all env-var driven factories

### Configuration Module

`config.py` is a flat module of constants read from environment variables at import time. No classes. All values are module-level. Tests patch via `monkeypatch.setattr(main.config, ...)` or `monkeypatch.setenv(...)` + reimport.

### Dataclasses (immutable state)

- `BatteryState` (`bms/daly.py`) — voltage, current, SOC, cells, temps
- `IMUSample` (`imu/__init__.py`) — gyro_z_dps, accel_x/y/z_g, timestamp
- `AssistedDriveConfig`, `AssistedDriveResult` (`motors/assisted_drive.py`) — frozen PID config and per-tick result
- `PidTuningSnapshot` (`pid_tuning.py`) — 8 PID parameters, serializable to JSON
- `MotorCurrentSample`, `MotorLimitConfig`, `MotorLimitResult` (`motors/current_control.py`)
- `STM32LinkConfig` (`stm32_link/client.py`) — SPI bus params

---

## Component Boundaries
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

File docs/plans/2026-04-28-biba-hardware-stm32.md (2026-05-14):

# biba_hardware_stm32 Implementation Plan

> **For Claude:** REQUIRED SUB-SKILL: Use `superpowers:executing-plans` to implement this plan task-by-task.

**Goal:** Promote `biba_hardware_stm32` from a skeleton to a working `ros2_control` `SystemInterface` so `diff_drive_controller` can drive the robot directly through SPI without a Python hop.

**Architecture:**
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

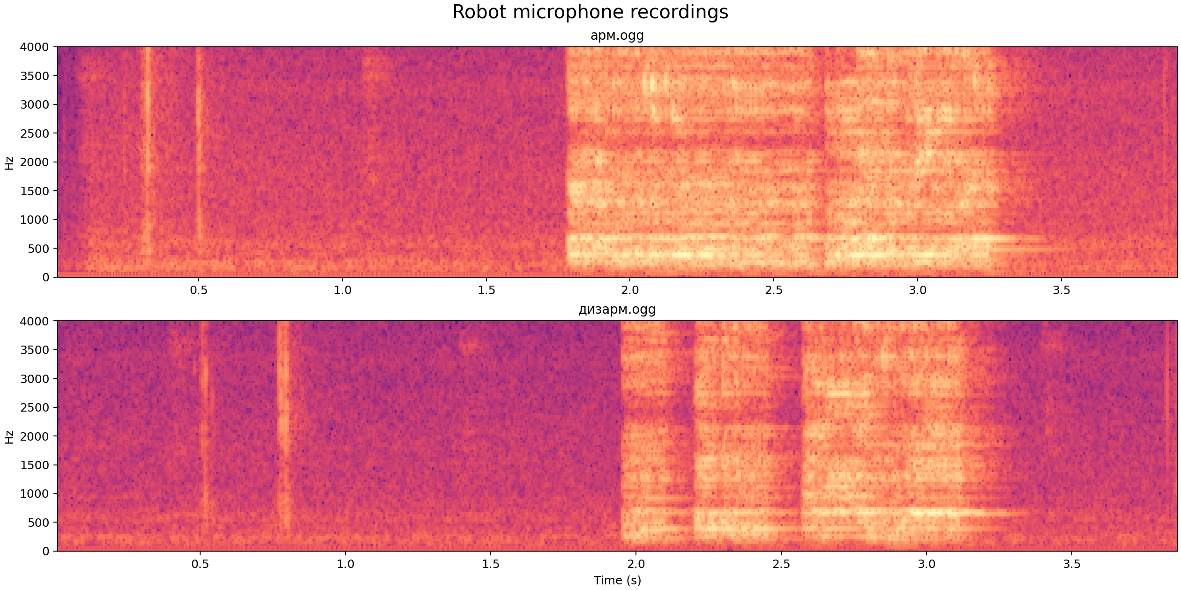
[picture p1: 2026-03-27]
docs/robot-recordings-spectrograms-2026-03-27.png

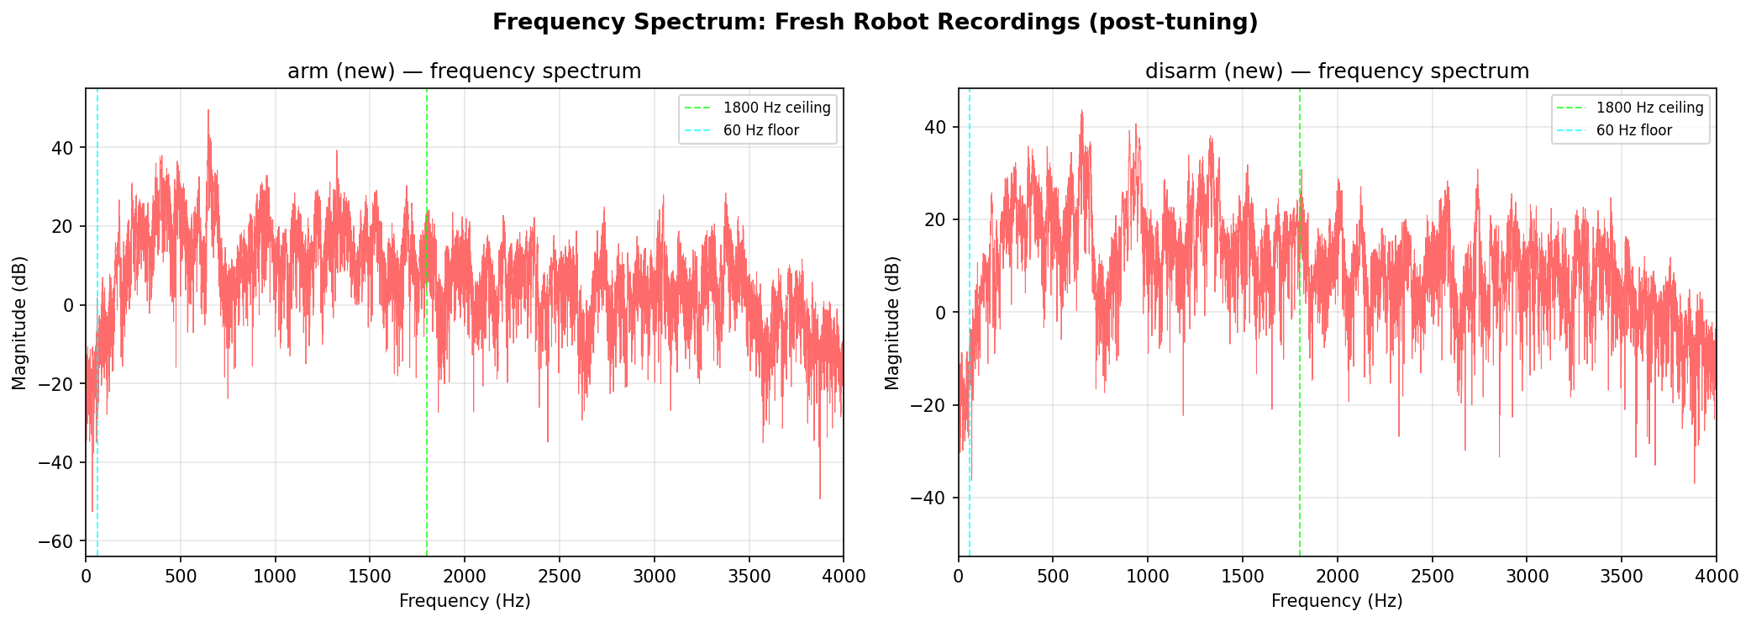
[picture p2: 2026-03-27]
docs/robot-recordings-spectrum-post-tuning-2026-03-27.png

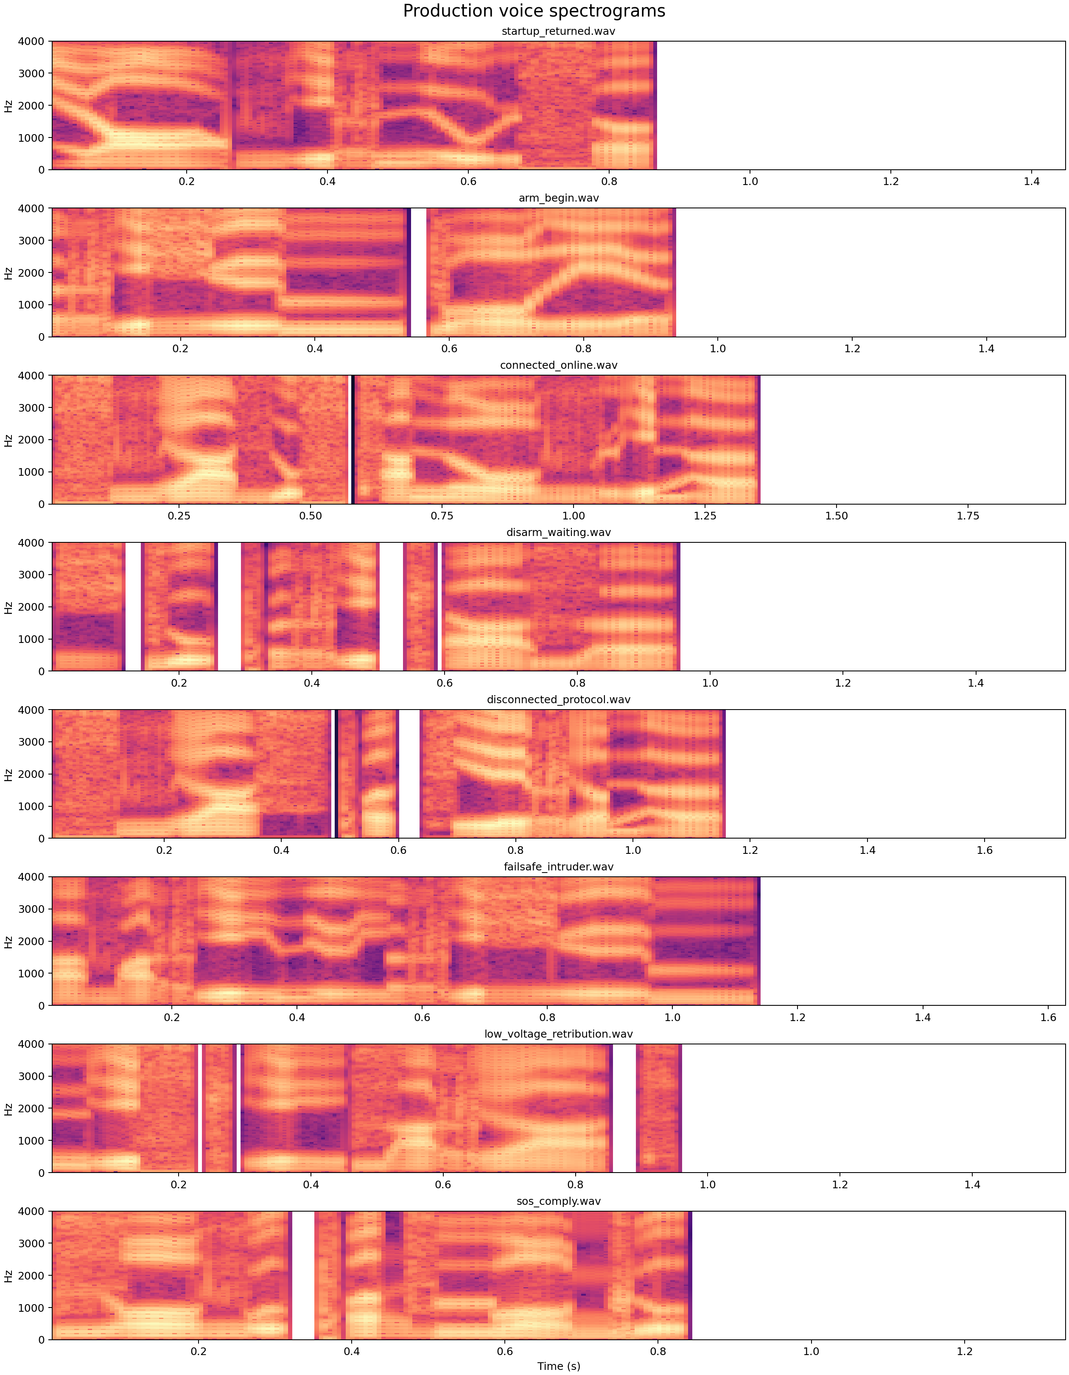
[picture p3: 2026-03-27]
docs/voice-spectrograms-2026-03-27.png

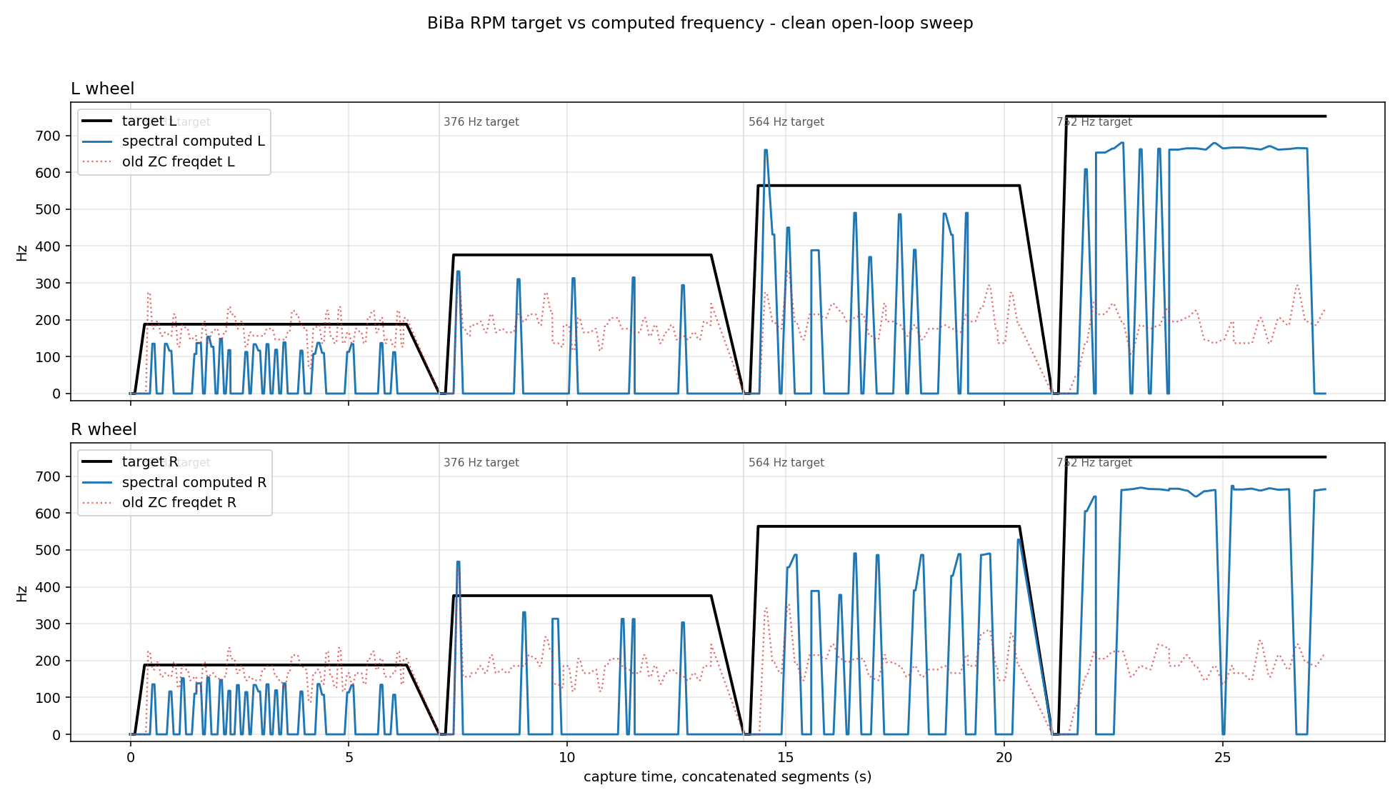
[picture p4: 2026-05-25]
scripts/artifacts/drive-capture/target_vs_computed_specdiag_20260524_195519.png

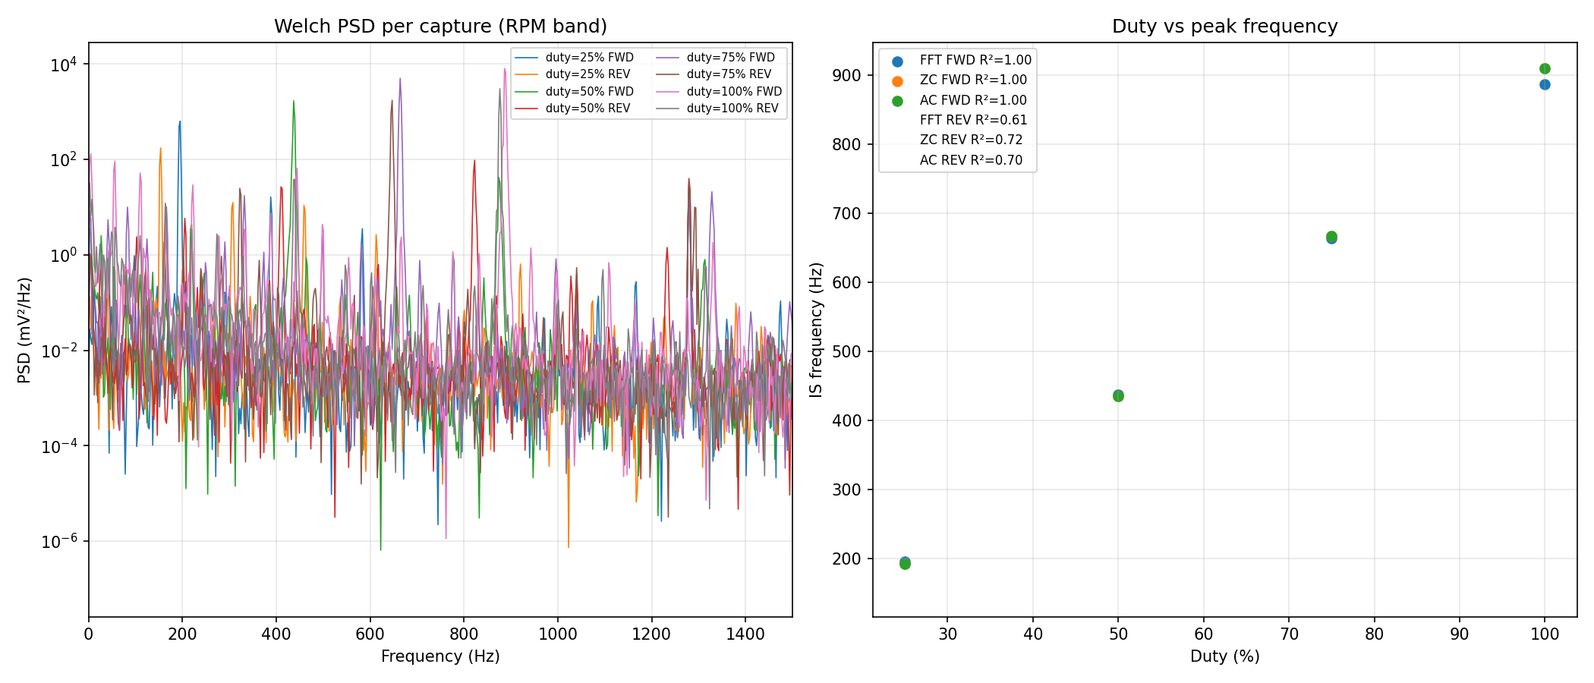
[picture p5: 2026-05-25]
scripts/artifacts/is-capture/is_spectrum_analysis.png

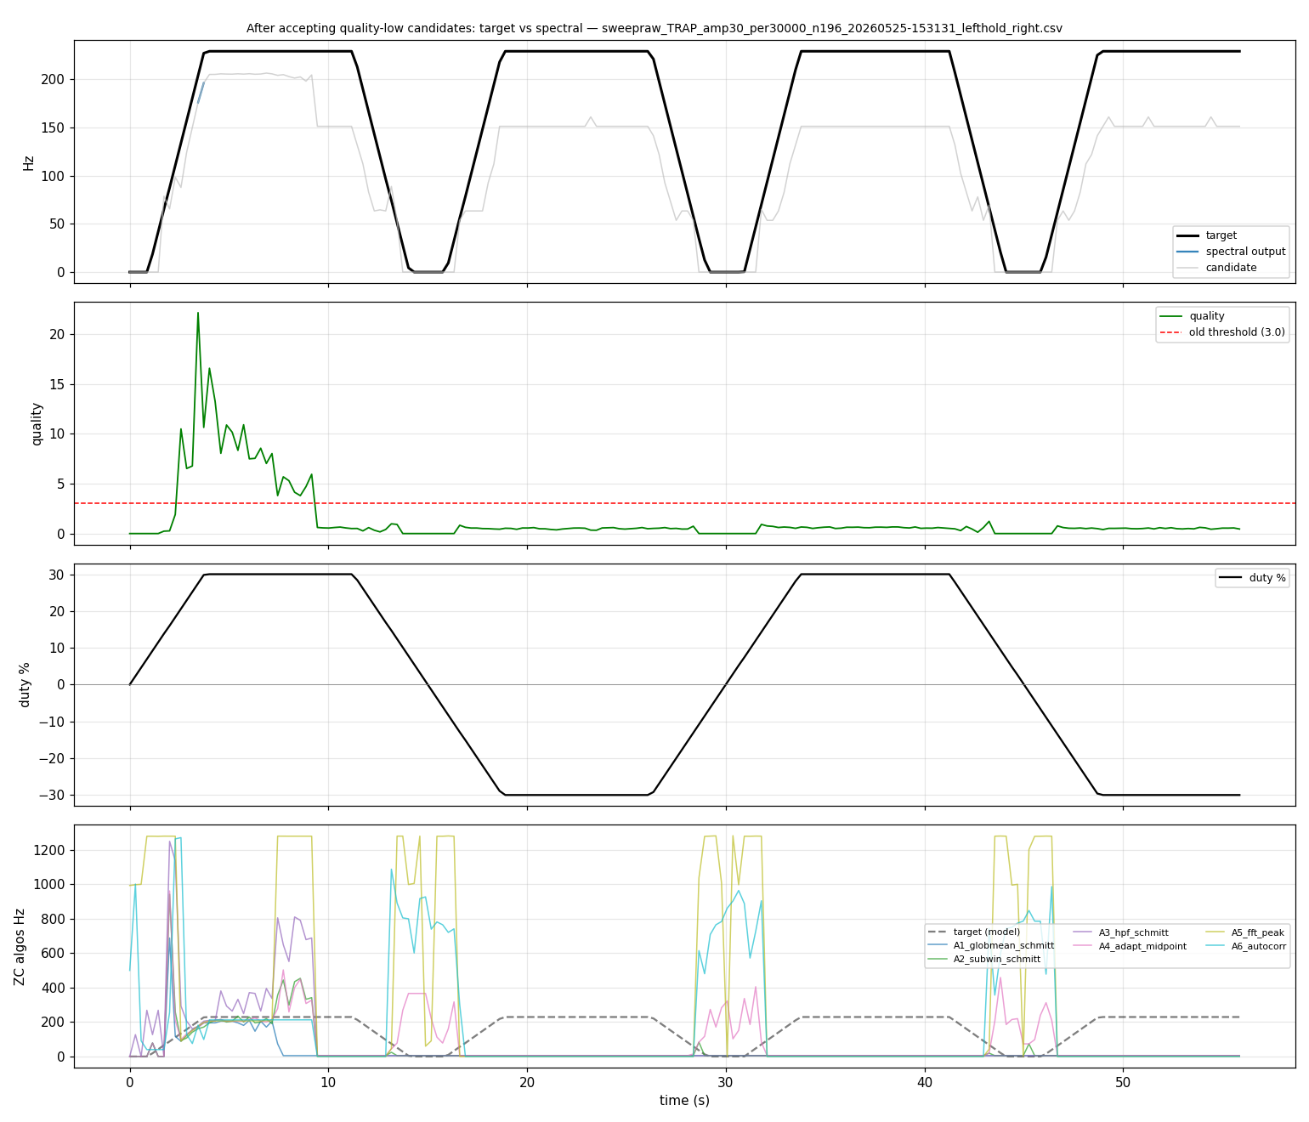
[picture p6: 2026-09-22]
scripts/artifacts/is-sweepraw/sweepraw_TRAP_amp30_per30000_n196_20260525-153131_lefthold_spectral_right.png

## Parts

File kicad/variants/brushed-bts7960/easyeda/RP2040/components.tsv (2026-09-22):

designator | value | package | lcsc | mfr_part | pins | rotation | x | y | link
C1 | 0.1u | C0805 |  |  | 2 | 90 | 4201.5 | 3517 | https://item.szlcsc.com/373011.html
C2 | 0.1u | C0805 |  |  | 2 | 180 | 4300 | 3525 | https://item.szlcsc.com/373011.html
C3 | 0.1u | C0805 |  |  | 2 | 180 | 4300 | 3605 | https://item.szlcsc.com/373011.html
C4 | 0.1u | C0805 |  |  | 2 | 270 | 4224 | 3675 | https://item.szlcsc.com/373011.html
C5 | 0.1u | C0805 |  |  | 2 | 270 | 4254 | 3675 | https://item.szlcsc.com/373011.html
C6 | 0.1u | C0805 |  |  | 2 | 180 | 4156 | 3482 | https://item.szlcsc.com/373011.html
C7 | 1uF | C0603 |  |  | 2 | 90 | 4190 | 3488.5 | https://item.szlcsc.com/362304.html
C8 | 2.2uF | C0603 |  |  | 2 | 270 | 4159 | 3465.5 | https://item.szlcsc.com/362304.html
C9 | 1000uF | CAP-TH_BD16.0-P7.50-D0.8-FD-H25.0 | C51904448 | ERB50V1000M16X25 | 2 | 180 | 4320 | 3683 | https://atta.szlcsc.com/upload/public/pdf/source/20250912/46A302DCA73B95C19C2446BC821F7B24.pdf
H1 | HDR-F-2.54_1x3 | HDR-F-2.54_1X3 | C146690 |  | 3 | 90 | 4095 | 3430 | https://www.cjt.com/Upload/A2541.pdf
H2 | HDR-F-2.54_1x3 | HDR-F-2.54_1X3 | C146690 |  | 3 | 90 | 4105 | 3430 | https://www.cjt.com/Upload/A2541.pdf
H3 | HDR-F-2.54_1x3 | HDR-F-2.54_1X3 | C146690 |  | 3 | 90 | 4115 | 3430 | https://www.cjt.com/Upload/A2541.pdf
H4 | HDR-F-2.54_1x3 | HDR-F-2.54_1X3 | C146690 |  | 3 | 90 | 4125 | 3430 | https://www.cjt.com/Upload/A2541.pdf
H5 | HDR-F-2.54_1x3 | HDR-F-2.54_1X3 | C146690 |  | 3 | 90 | 4055 | 3430 | https://www.cjt.com/Upload/A2541.pdf
H6 | HDR-F-2.54_1x3 | HDR-F-2.54_1X3 | C146690 |  | 3 | 90 | 4065 | 3430 | https://www.cjt.com/Upload/A2541.pdf
H7 | HDR-F-2.54_1x3 | HDR-F-2.54_1X3 | C146690 |  | 3 | 90 | 4075 | 3430 | https://www.cjt.com/Upload/A2541.pdf
H8 | HDR-F-2.54_1x3 | HDR-F-2.54_1X3 | C146690 |  | 3 | 90 | 4085 | 3430 | https://www.cjt.com/Upload/A2541.pdf
H10 | HDR-F-2.54_1x3 | HDR-F-2.54_1X3 | C146690 |  | 3 | 180 | 4239 | 3699 | https://www.cjt.com/Upload/A2541.pdf
IC1 | rp2040_RP2040_breakout_swd | RP2040:RP2040-BREAKOUT_SWD |  |  | 44 | 180 | 4091.5 | 3581
J1 | HDR-M-2.54_1x3 | HDR-M-2.54_1X3 | C180248 |  | 3 | 90 | 4170 | 3383.5
J2 | HDR-M-2.54_1x4 | HDR-M-2.54_1X4 | C124378 |  | 4 | 180 | 4160 | 3341.5
J3 | HDR-M-2.54_1x4 | HDR-M-2.54_1X4 | C124378 |  | 4 |  | 4174.5 | 3698.5
J4 | HDR-M-2.54_1x4 | HDR-M-2.54_1X4 | C124378 |  | 4 | 180 | 4100 | 3341.5
PM1 | SKMW30f-05 | SKMW30G-05 |  |  | 6 | 90 | 4299 | 3433.5
R1 | 30k | R0805 |  |  | 2 | 90 | 4211.5 | 3597 | https://item.szlcsc.com/142685.html
R2 | 30k | R0805 |  |  | 2 | 90 | 4221.5 | 3597 | https://item.szlcsc.com/142685.html
R3 | 30k | R0805 |  |  | 2 | 90 | 4231.5 | 3597 | https://item.szlcsc.com/142685.html
R4 | 30k | R0805 |  |  | 2 | 90 | 4241.5 | 3597 | https://item.szlcsc.com/142685.html
R5 | 30k | R0805 |  |  | 2 | 270 | 4241.5 | 3517 | https://item.szlcsc.com/142685.html
R6 | 30k | R0805 |  |  | 2 | 270 | 4231.5 | 3517 | https://item.szlcsc.com/142685.html
R7 | 30k | R0805 |  |  | 2 | 270 | 4221.5 | 3517 | https://item.szlcsc.com/142685.html
R8 | 30k | R0805 |  |  | 2 | 270 | 4211.5 | 3517 | https://item.szlcsc.com/142685.html
R9 | 10k | R0805 |  |  | 2 |  | 4300 | 3585 | https://item.szlcsc.com/142685.html
R10 | 10k | R0805 |  |  | 2 |  | 4300 | 3575 | https://item.szlcsc.com/142685.html
R11 | 10k | R0805 |  |  | 2 |  | 4300 | 3505 | https://item.szlcsc.com/142685.html
R12 | 10k | R0805 |  |  | 2 |  | 4300 | 3495 | https://item.szlcsc.com/142685.html
R13 | 10k | R0805 |  |  | 2 |  | 4300 | 3545 | https://item.szlcsc.com/142685.html
R14 | 10k | R0805 |  |  | 2 | 180 | 4300 | 3535 | https://item.szlcsc.com/142685.html
R15 | 10k | R0805 |  |  | 2 | 180 | 4300 | 3625 | https://item.szlcsc.com/142685.html
R16 | 10k | R0805 |  |  | 2 |  | 4300 | 3615 | https://item.szlcsc.com/142685.html
R17 | 1k | R0805 |  |  | 2 |  | 4300 | 3515 | https://item.szlcsc.com/142685.html
R18 | 1k | R0805 |  |  | 2 |  | 4300 | 3555 | https://item.szlcsc.com/142685.html
R19 | 1k | R0805 |  |  | 2 |  | 4300 | 3595 | https://item.szlcsc.com/142685.html
R20 | 1k | R0805 |  |  | 2 |  | 4300 | 3635 | https://item.szlcsc.com/142685.html
R21 | 10k | R0603 |  |  | 2 | 180 | 4194 | 3477 | https://www.mouser.in/datasheet/2/447/PYu_RT_1_to_0_01_RoHS_L_11-1669912.pdf
R22 | 10k | R0603 |  |  | 2 |  | 4194 | 3469 | https://www.mouser.in/datasheet/2/447/PYu_RT_1_to_0_01_RoHS_L_11-1669912.pdf
R23 | 10k | R0603 |  |  | 2 |  | 4194 | 3460 | https://www.mouser.in/datasheet/2/447/PYu_RT_1_to_0_01_RoHS_L_11-1669912.pdf
R24 | 10k | R0603 |  |  | 2 |  | 4184.5 | 3450 | https://www.mouser.in/datasheet/2/447/PYu_RT_1_to_0_01_RoHS_L_11-1669912.pdf
R25 | 1k | R0805 |  |  | 2 | 270 | 4234 | 3675 | https://item.szlcsc.com/142685.html
R26 | 1k | R0805 |  |  | 2 | 270 | 4244 | 3675 | https://item.szlcsc.com/142685.html
U1 | SN74AHC244DW | SOIC-20_L12.8-W7.5-P1.27-LS10.3-BL | C1548445 | SN74AHC244DW | 20 |  | 4223 | 3557.5 | https://atta.szlcsc.com/upload/public/pdf/source/20210720/C906746_0CC5C426796129A62340EE6012BC95AE.pdf
U2 | BTN7970 | TO-263-7_L10.2-W10.4-P1.27-LS14.4-B |  |  | 8 | 180 | 4400.5 | 3375
U3 | BTN7970 | TO-263-7_L10.2-W10.4-P1.27-LS14.4-B |  |  | 8 | 180 | 4400.666 | 3472
U4 | BTN7970 | TO-263-7_L10.2-W10.4-P1.27-LS14.4-B |  |  | 8 | 180 | 4401 | 3569.5
U5 | BTN7970 | TO-263-7_L10.2-W10.4-P1.27-LS14.4-B |  |  | 8 | 180 | 4400 | 3666.5
U6 | BMI160 | LGA-14_L3.0-W2.5-P0.50-BL | C94021 | BMI160 | 14 | 180 | 4175 | 3465.5 | https://lcsc.com/product-detail/Sensors_Bosch_BMG250_BMG250_C189521.html
U7 | SPX3819M5-L-3-3/TR | SOT-23-5_L3.0-W1.7-P0.95-LS2.8-BR | C9055 | SPX3819M5-L-3-3/TR | 5 | 270 | 4175.5 | 3487.5

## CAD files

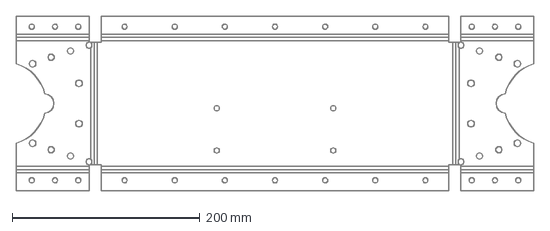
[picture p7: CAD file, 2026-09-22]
firmware/docs/cad/dxf/MAIN_BRIDGE.dxf
550.6 x 185.6 mm

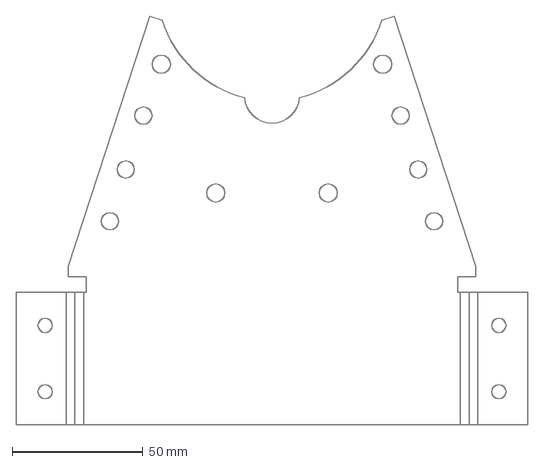
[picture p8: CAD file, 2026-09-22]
firmware/docs/cad/dxf/MOTOR_MOUNT_R.dxf
195.6 x 156.5 mm

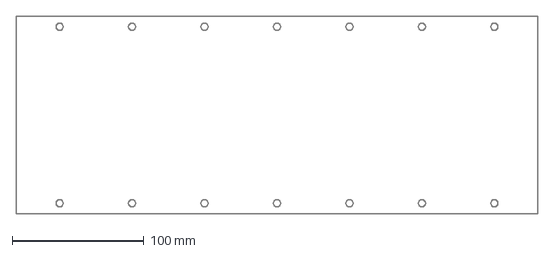
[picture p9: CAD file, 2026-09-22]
firmware/docs/cad/dxf/COVER_TOP.dxf
396.0 x 150.0 mm

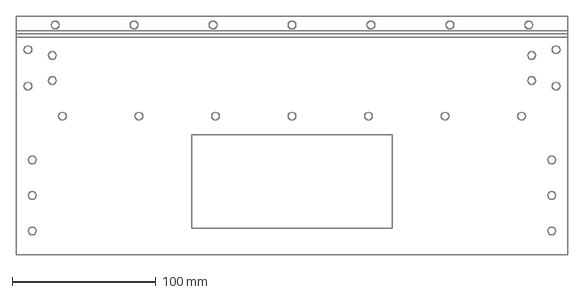
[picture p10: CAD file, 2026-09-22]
firmware/docs/cad/dxf/PANEL_FORE.dxf
384.0 x 166.0 mm

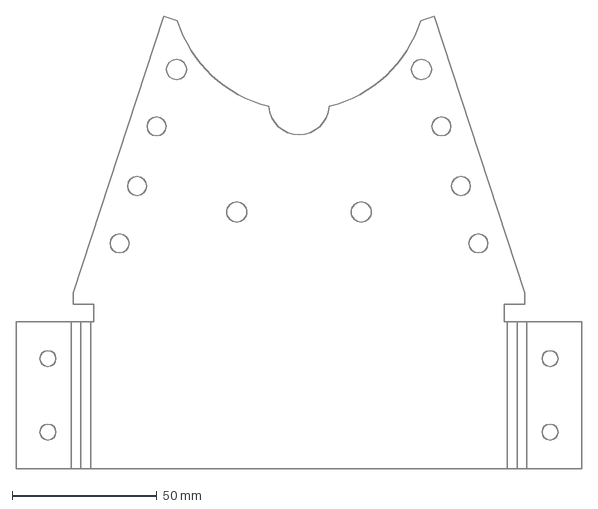
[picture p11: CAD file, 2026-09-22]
firmware/docs/cad/dxf/MOTOR_MOUNT_L.dxf
195.6 x 156.5 mm

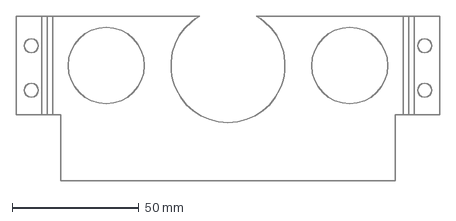
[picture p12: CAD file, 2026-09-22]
firmware/docs/cad/dxf/BULKHEAD_L.dxf
167.0 x 65.0 mm

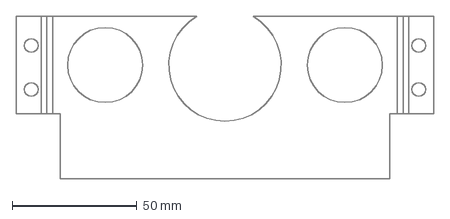
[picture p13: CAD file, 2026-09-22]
firmware/docs/cad/dxf/BULKHEAD_R.dxf
167.0 x 65.0 mm

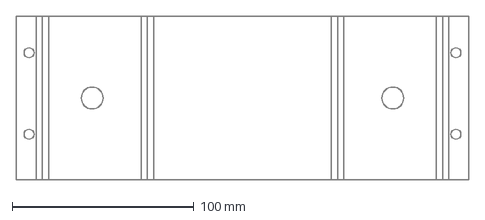
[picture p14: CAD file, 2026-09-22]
firmware/docs/cad/dxf/DOCK_SOCKET.dxf
249.1 x 90.0 mm

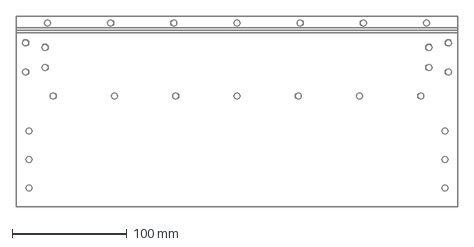
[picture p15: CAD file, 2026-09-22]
firmware/docs/cad/dxf/PANEL_AFT.dxf
384.0 x 166.0 mm

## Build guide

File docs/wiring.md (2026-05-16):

# Подключение

## Распиновка Raspberry Pi Zero 2W

| Назначение | GPIO BCM | Физический пин |
| --- | --- | --- |
| ELRS TX (Pi -> RX приемника) | 14 | 8 |
| ELRS RX (Pi <- TX приемника) | 15 | 10 |
| I2C SDA (ADS1115 / BMI160, опционально) | 2 | 3 |
| I2C SCL (ADS1115 / BMI160, опционально) | 3 | 5 |
| Left BTS7960 RPWM | 12 | 32 |
| Left BTS7960 LPWM | 18 | 12 |
| Left BTS7960 REN | 23 | 16 |
| Left BTS7960 LEN | 24 | 18 |
| Right BTS7960 RPWM | 19 | 35 |
| Right BTS7960 LPWM | 13 | 33 |
| Right BTS7960 REN | 20 | 38 |
| Right BTS7960 LEN | 21 | 40 |
| GND драйвера | - | 14 |

## Статус текущей двухмоторной проводки

Текущая распиновка выше считается рабочей эксплуатационной схемой для двух BTS7960 на Pi Zero 2W.

- `LEFT RPWM=12` и `LEFT LPWM=18` делят hardware PWM channel 0.
- `RIGHT RPWM=19` и `RIGHT LPWM=13` делят hardware PWM channel 1.
- Поэтому для одновременной работы двух моторов с этой проводкой нужно явно выставлять `BTS7960_PWM_MODE=SOFTWARE`.

Пример текущего runtime-конфига:

```ini
BTS7960_PWM_MODE=SOFTWARE
LEFT_MOTOR_ENABLED=1
RIGHT_MOTOR_ENABLED=1
LEFT_MOTOR_RPWM=12
LEFT_MOTOR_LPWM=18
RIGHT_MOTOR_RPWM=19
RIGHT_MOTOR_LPWM=13
```

## Целевая hardware-PWM конфигурация

Кодовый дефолт `BTS7960_PWM_MODE=SOFTWARE` оставлен намеренно: это безопасный режим для текущей рабочей проводки.

Для Raspberry Pi Zero 2W это означает одно из двух:

- либо включён только один BTS7960-мотор на паре `RPWM/LPWM`, использующей разные hardware-каналы;
- либо двухмоторная схема переведена на внешний PWM-генератор или другой драйвер, который не требует четырёх независимых hardware-PWM линий от самой Pi.

С текущей проводкой `12/18` и `19/13` режим `HARDWARE` для двух моторов использовать нельзя.

## Подключение current sense через ADS1115

Для ограничения по току и вывода токов колёс в телеметрию контроллер может читать BTS7960 `IS`-линии через ADS1115.

Рекомендуемая схема первого варианта:

| Сигнал | Куда подключать |
| --- | --- |
| ADS1115 VDD | 3.3V Raspberry Pi |
| ADS1115 GND | GND Raspberry Pi |
| ADS1115 SDA | GPIO 2 / pin 3 |
| ADS1115 SCL | GPIO 3 / pin 5 |
| Left BTS7960 `R_IS` | ADS1115 A2 |
| Left BTS7960 `L_IS` | ADS1115 A3 |
| Right BTS7960 `R_IS` | ADS1115 A0 |
| Right BTS7960 `L_IS` | ADS1115 A1 |
| Общая земля силовой части | Общая с GND Raspberry Pi и ADS1115 |

Текущая реализация использует по два ADS1115-канала на мотор: отдельный sense-вход для прямого и обратного направления. Активный канал выбирается по знаку duty в рантайме.

## Подключение IMU для stabilized / heading-hold

Новый stabilized / heading-hold режим использует IMU на том же `I2C-1`, что и ADS1115. Контроллер умеет autodetect для двух семейств датчиков: BMI160/BMI166 и ST LSM6DS3-class. Датчик можно вешать на общие `SDA/SCL`, если его адрес не конфликтует с `0x48` ADS1115.

Рекомендуемая схема подключения:

| Сигнал | Куда подключать |
| --- | --- |
| IMU VDD | 3.3V Raspberry Pi |
| IMU GND | GND Raspberry Pi |
| IMU SDA | GPIO 2 / pin 3 |
| IMU SCL | GPIO 3 / pin 5 |
| IMU ADDR/SDO/SA0 | По схеме модуля; BMI обычно `0x68/0x69`, ST LSM6DS3-class обычно `0x6A/0x6B` |

Минимальный env-набор для включения IMU:

```ini
IMU_ENABLED=1
IMU_I2C_BUS=1
IMU_I2C_ADDRESS=104
IMU_EXPECTED_CHIP_ID=209
IMU_SAMPLE_RATE_HZ=100.0
IMU_STALE_TIMEOUT_S=0.2
IMU_GYRO_BIAS_CALIBRATION_S=1.0
IMU_GYRO_Z_SIGN=1.0
```

На текущем роботе probing показал ST LSM6DS3-class модуль на `0x6A`, так что для него нужно переопределить `IMU_I2C_ADDRESS=106`.

Если IMU установлена развернутой по yaw-оси, поменяйте `IMU_GYRO_Z_SIGN` на `-1.0` вместо перепайки.

## Env-переменные current sense и limiter

Минимальный набор для включения функции:

```ini
MOTOR_CURRENT_SENSE_ENABLED=1
MOTOR_CURRENT_LIMITING_ENABLED=1
MOTOR_CURRENT_SENSE_I2C_ADDRESS=72
LEFT_MOTOR_CURRENT_SENSE_FORWARD_CHANNEL=2
LEFT_MOTOR_CURRENT_SENSE_REVERSE_CHANNEL=3
RIGHT_MOTOR_CURRENT_SENSE_FORWARD_CHANNEL=0
RIGHT_MOTOR_CURRENT_SENSE_REVERSE_CHANNEL=1
MOTOR_CURRENT_SENSE_GAIN=1
MOTOR_CURRENT_SENSE_SAMPLE_RATE_HZ=32
LEFT_MOTOR_MAX_CURRENT_A=18
RIGHT_MOTOR_MAX_CURRENT_A=18
LEFT_MOTOR_MAX_POWER_W=180
RIGHT_MOTOR_MAX_POWER_W=180
MOTOR_LIMIT_FALLBACK_VOLTAGE=24.0
LEFT_MOTOR_CURRENT_SENSE_ZERO_OFFSET_V=0.0
RIGHT_MOTOR_CURRENT_SENSE_ZERO_OFFSET_V=0.0
LEFT_MOTOR_CURRENT_SENSE_AMPS_PER_VOLT=1.0
RIGHT_MOTOR_CURRENT_SENSE_AMPS_PER_VOLT=1.0
```

Назначение:

- `MOTOR_CURRENT_SENSE_ENABLED=1` включает чтение ADS1115.
- `MOTOR_CURRENT_LIMITING_ENABLED=1` включает уменьшение PWM по measured current/power.
- `*_FORWARD_CHANNEL` и `*_REVERSE_CHANNEL` задают ADS1115-каналы для каждого направления каждого мотора.
- `*_MAX_CURRENT_A` ограничивают ток каждого мотора независимо.
- `*_MAX_POWER_W` ограничивают мощность каждого мотора независимо.
- `MOTOR_LIMIT_FALLBACK_VOLTAGE` используется для расчёта мощности, если Daly BMS временно недоступен.
- `*_ZERO_OFFSET_V` и `*_AMPS_PER_VOLT` задают калибровку конкретного BTS7960-модуля.

Если нужно только видеть токи колёс в телеметрии, а резать PWM пока не нужно, оставьте:

```ini
MOTOR_CURRENT_SENSE_ENABLED=1
MOTOR_CURRENT_LIMITING_ENABLED=0
```

Для калибровочных прогонов можно отдельно включить trace-файл:

```ini
MOTOR_CURRENT_TRACE_ENABLED=1
MOTOR_CURRENT_TRACE_PATH=/data/current-trace.jsonl
MOTOR_CURRENT_TRACE_POST_ROLL_S=2.0
MOTOR_CURRENT_TRACE_MIN_INTERVAL_S=0.0
```

Назначение:

- `MOTOR_CURRENT_TRACE_ENABLED=1` включает JSONL-трейс в основном controller loop.
- `MOTOR_CURRENT_TRACE_PATH` задаёт путь файла на persistent volume.
- `MOTOR_CURRENT_TRACE_POST_ROLL_S` помогает поймать запаздывающий ток BMS после окончания движения.
- `MOTOR_CURRENT_TRACE_MIN_INTERVAL_S` позволяет ограничить частоту записи, если trace становится слишком плотным.

## Калибровка BTS7960 `IS`

`IS` у BTS7960 на дешёвых модулях нельзя считать абсолютно точным датчиком без калибровки. Для первого запуска используйте такой порядок:

1. Включите только измерение, без limiter:
	`MOTOR_CURRENT_SENSE_ENABLED=1`, `MOTOR_CURRENT_LIMITING_ENABLED=0`.
2. Оставьте мотор без нагрузки и снимите напряжение на `IS`.
	Это значение запишите в `LEFT_MOTOR_CURRENT_SENSE_ZERO_OFFSET_V` и `RIGHT_MOTOR_CURRENT_SENSE_ZERO_OFFSET_V`.
3. Дайте известную нагрузку и измерьте реальный ток внешним прибором.
4. Посчитайте коэффициент:

$$
amps\_per\_volt = \frac{I_{measured}}{V_{is} - V_{offset}}
$$

5. Запишите коэффициенты в `LEFT_MOTOR_CURRENT_SENSE_AMPS_PER_VOLT` и `RIGHT_MOTOR_CURRENT_SENSE_AMPS_PER_VOLT`.
6. После этого включайте `MOTOR_CURRENT_LIMITING_ENABLED=1` и подбирайте `*_MAX_CURRENT_A` и `*_MAX_POWER_W` уже по реальным данным.

## Примечания

- Для Phase 3 thermal reset на BTS7960 используется EN/INH путь (REN/LEN) с 100 us LOW-пульсом и нулевым PWM во время reset; подробный протокол проверки см. в [field-validation.md](field-validation.md).
- Каноническая матрица статуса поддерживаемых платформ и ссылок на реализацию: [variants.md](variants.md).

- Включите основной UART на Raspberry Pi и освободите его от Bluetooth перед использованием CRSF на скорости 420000 бод.
- Daly BMS подключается по BLE или через USB-UART адаптер и обычно появляется как `/dev/ttyUSB0` в UART-режиме.
- Для BTS7960 каждый мотор использует две линии PWM (`RPWM` и `LPWM`) и две линии enable (`REN`, `LEN`).
- Звуковая индикация и voice playback в текущей конфигурации идут через моторы, отдельный buzzer не требуется.
- Для Ubuntu на Raspberry Pi включите I2C через `/boot/firmware/config.txt` или `/boot/firmware/usercfg.txt`: добавьте строку `dtparam=i2c_arm=on`, перезагрузите плату и проверьте наличие `/dev/i2c-1`.
- Для ухода от слышимого свиста software PWM желательно временно оставить только как workaround. Полный hardware PWM на двух BTS7960 с текущими GPIO `12`, `13`, `18`, `19` конфликтует по shared channels.
- Если на конкретной плате `REN` и `LEN` объединены, это можно переопределить одинаковыми значениями в env-конфигурации.
- Если `IS` не выведен наружу на вашем BTS7960-модуле, текущая реализация current sense не заработает: нужен либо другой модуль, либо отдельный датчик тока.
- Земля силовой части и земля Raspberry Pi должны быть объединены.
- Если одно из колёс вращается в неверную сторону, это можно исправить без перепайки через `MOTOR1_INVERTED` или `MOTOR2_INVERTED` в compose-конфигурации.

## Рекомендуемая конфигурация Raspberry Pi

Добавьте следующие строки в `/boot/firmware/config.txt` или `/boot/config.txt` в зависимости от образа системы:

```ini
enable_uart=1
dtoverlay=disable-bt
```

После этого отключите serial console, если она включена, и перезагрузите плату.

Для Ubuntu на Raspberry Pi I2C обычно включается так:

```bash
sudo apt update
sudo apt install -y i2c-tools
sudoedit /boot/firmware/config.txt
```

Добавьте строку:

```ini
dtparam=i2c_arm=on
```

Если в `config.txt` уже подключается `usercfg.txt`, можно положить эту строку туда вместо правки основного файла.

После перезагрузки проверьте:

```bash
ls /dev/i2c-*
sudo i2cdetect -y 1
```

Для ADS1115 по умолчанию ожидается адрес `0x48`, поэтому в выводе `i2cdetect` обычно должен появиться `48`.
Для BMI160/BMI166-compatible IMU обычно ожидается `0x68` или `0x69`, для ST LSM6DS3-class чаще `0x6A` или `0x6B`, так что в таблице `i2cdetect` должен появиться ещё один адрес рядом с ADS1115.
## Подключение STM32F103

Прошивка [firmware](../firmware) — опциональный
STM32F103C8T6 ("Blue Pill") добавочный контроллер, который умеет
работать либо самостоятельно (CRSF + BTS7960 + лимитер), либо
SPI-slave к Raspberry Pi. Подробности — в
[docs/stm32_architecture.md](stm32_architecture.md).

Выбор режима жёстко определяется сборочным env (`standalone` /
`companion`) или пином `MODE_SEL` (только в env `combined`).

### Распиновка STM32F103C8T6 (target `BLUEPILL_F103C8`)

Это эталонная распиновка target'а `BLUEPILL_F103C8`
(см. [`firmware/targets/BLUEPILL_F103C8/target.md`](../firmware/targets/BLUEPILL_F103C8/target.md)).
Другие target'ы (например, `BIBA_F103_REV_A`) могут назначать эти
функции на другие пины — всегда сверяйтесь с `target.md` конкретной
платы, которую собираете.

| Назначение | Пин STM32  |
| --- | --- |
| TIM1_CH1 — Left RPWM | PA8 |
| TIM1_CH2 — Left LPWM | PA9 |
| TIM1_CH3 — Right RPWM | PA10 |
| TIM1_CH4 — Right LPWM | PA11 |
| Left BTS7960 R_EN / L_EN | PB3 / PB4  |
| Right BTS7960 R_EN / L_EN | PB5 / PB8  |
| ADC1 IN0..IN3 — 4× BTS7960 `IS` (L+R, L+R) | PA0..PA3 |
| ADC1 IN4 — VBAT через делитель 1:11 | PA4 |
| ADC1 IN5 — опционально 12V rail (1:11) | PA5 |
| ADC1 IN6 — резерв | PA6 |
| SPI2 NSS / SCK / MISO / MOSI (slave к SBC) | PB12 / PB13 / PB14 / PB15 |
| USART3 TX / RX — CRSF | PB10 / PB11 |
| I2C1 SCL / SDA — IMU | PB6 / PB7  |
| DATA_READY → SBC (GPIO-прерывание) | PA12 |
| MODE_SEL (pull-up; GND = companion) | PB9 |
| Status LED (on-board blue pill) | PC13 |
| SWD (оставлять для прошивки / отладки) | PA13 / PA14 |

Конкретные значения собраны в `firmware/include/biba_board.h` и
`include/biba_config.h` — там же настраиваются частота PWM,
current-sense калибровка и таймауты failsafe.

### Нюансы, которые легко пропустить

- `USART1` на стандартных пинах `PA9/PA10` конфликтует с TIM1_CH2/CH3
  и не используется. CRSF едет через `USART3` (PB10/PB11).
- Перед тем как PB3/PB4/PA15 заработают как GPIO, прошивка отключает
  JTAG в `biba_hal_init()` (SWD остаётся доступен для прошивки).
  Поэтому `Left R_EN`=PB3 и `Left L_EN`=PB4 — это освобождённые
  JTAG-пины; если вы не отпускаете JTAG, перенесите enable-пины в
  `biba_board.h`.
- BTS7960 питаются отдельным силовым 5V/6V, а земля должна быть общей с
  STM32. VCC BOARD на STM32 — с 3.3V линии USB-UART программатора или
  с BEC.
- **Motor-audio требует target с четырьмя независимыми таймерами PWM.**
  `BLUEPILL_F103C8` держит все 4 канала на TIM1 — одна несущая, звук
  через колёса невозможен. Для motor-audio (voice playback / мелодии
  через BTS7960) используйте target `BIBA_F103_REV_A`: у него
  `L_RPWM=TIM1_CH1`, `L_LPWM=TIM2_CH1` (remap на PA15),
  `R_RPWM=TIM3_CH4`, `R_LPWM=TIM4_CH4`, что даёт 4 независимых
  частоты/duty одновременно. Подробная распиновка — в
  [`firmware/targets/BIBA_F103_REV_A/target.md`](../firmware/targets/BIBA_F103_REV_A/target.md).

### SPI к Raspberry Pi (companion mode)

| STM32 | Pi GPIO (BCM) | Физический пин Pi |
| --- | --- | --- |
| SPI2 NSS  | GPIO 8 (CE0)  | 24 |
| SPI2 SCK  | GPIO 11 | 23 |
| SPI2 MOSI | GPIO 10 | 19 |
| SPI2 MISO | GPIO 9 | 21 |
| DATA_READY| GPIO 25 | 22 (опциональное IRQ) |
| GND | GND | 20 |

Для включения SPI-моста выставьте `STM32_LINK_ENABLED=1` в env-файле
Pi-runtime (см. `biba-controller/config.py`).

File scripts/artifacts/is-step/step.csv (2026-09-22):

t_ms | phase | duty_pct | meas_hz | curr_a
103 | PRE | 0.0 | 0.00 | -0.00
207 | PRE | 0.0 | 0.00 | -0.00
310 | PRE | 0.0 | 0.00 | 0.00
415 | PRE | 0.0 | 0.00 | 0.00
518 | PRE | 0.0 | 0.00 | -0.00
622 | POST | 50.0 | 68.36 | 55.08
726 | POST | 50.0 | 341.80 | 27.76
829 | POST | 50.0 | 361.33 | 13.63
933 | POST | 50.0 | 366.21 | 11.00
1037 | POST | 50.0 | 390.62 | 10.22
1141 | POST | 50.0 | 385.74 | 9.76
1245 | POST | 50.0 | 390.62 | 9.33
1349 | POST | 50.0 | 385.74 | 9.17
1452 | POST | 50.0 | 385.74 | 9.22
1556 | POST | 50.0 | 390.62 | 9.21
1660 | POST | 50.0 | 385.74 | 9.02
1764 | POST | 50.0 | 390.62 | 9.26
1868 | POST | 50.0 | 390.62 | 9.27
1972 | POST | 50.0 | 390.62 | 9.05
2076 | POST | 50.0 | 390.62 | 8.93
2180 | POST | 50.0 | 390.62 | 8.94
2283 | POST | 50.0 | 395.51 | 9.00
2387 | POST | 50.0 | 395.51 | 8.85
2491 | POST | 50.0 | 390.62 | 8.82
2595 | POST | 50.0 | 390.62 | 8.99

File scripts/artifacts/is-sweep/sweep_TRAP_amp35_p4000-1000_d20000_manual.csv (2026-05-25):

t_ms | duty_cmd_pct | meas_hz | curr_a | pkpk_adc | zc_count
0 | 0.0 | 0.00 | -0.00 | 34 | 0
105 | 7.4 | 0.00 | -0.15 | 31 | 0
209 | 14.7 | 0.00 | 4.93 | 399 | 1
315 | 22.3 | 0.00 | 10.56 | 1213 | 2
421 | 29.9 | 0.00 | 13.92 | 1115 | 2
526 | 35.0 | 0.00 | 12.69 | 1038 | 2
632 | 35.0 | 243.65 | 7.93 | 446 | 50
738 | 35.0 | 283.76 | 6.87 | 364 | 58
843 | 35.0 | 288.27 | 6.60 | 333 | 58
949 | 35.0 | 290.00 | 6.43 | 296 | 59
1054 | 35.0 | 293.52 | 6.36 | 285 | 59
1160 | 35.0 | 292.34 | 6.35 | 278 | 59
1266 | 35.0 | 292.04 | 6.40 | 299 | 60
1371 | 35.0 | 292.04 | 6.39 | 286 | 59
1477 | 30.5 | 94.94 | 5.01 | 101 | 16
1583 | 22.2 | 14.22 | 1.62 | 573 | 2
1688 | 13.9 | 12.22 | -0.55 | 415 | 2
1794 | 5.4 | 0.00 | -0.22 | 202 | 1
1900 | -3.2 | 28.41 | -0.31 | 51 | 2
2006 | -11.8 | 0.00 | -0.50 | 49 | 1
2112 | -20.6 | 0.00 | 7.81 | 678 | 1
2218 | -29.3 | 0.00 | 11.03 | 726 | 2
2323 | -35.0 | 0.00 | 11.01 | 603 | 2
2429 | -35.0 | 200.21 | 8.12 | 260 | 32
2535 | -35.0 | 253.04 | 7.43 | 242 | 52
2641 | -35.0 | 257.73 | 7.22 | 229 | 52
2746 | -35.0 | 258.96 | 7.25 | 225 | 51
2852 | -35.0 | 262.10 | 7.30 | 196 | 53
2958 | -35.0 | 261.83 | 7.33 | 180 | 54
3064 | -35.0 | 252.78 | 7.40 | 168 | 47
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

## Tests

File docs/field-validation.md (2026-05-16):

# Field Validation Protocol (Phase 3)

This protocol defines pass/fail evidence for Phase 3 field readiness.

## Hardware prerequisites

- BTS7960 modules are wired per [wiring.md](wiring.md).
- Common ground between controller and motor-power domains is confirmed.
- Motor power path and enable lines are electrically stable at idle.
- Current and telemetry capture paths are prepared:
  - `artifacts/current-trace/`
  - `artifacts/telemetry-captures/`
- Operator has a checklist copy and run ID for this session.

## Heat-sink installation evidence

Collect before any run:

- Photo of each BTS7960 mounted on a metal plate/heat sink.
- Photo showing thermal interface (pad/paste) and mechanical fixation.
- Note ambient temperature and weather conditions.
- Record run metadata (operator, date/time, battery pack ID, firmware revision).

## Thermal reset contract (locked decisions)

The brushed BTS7960 path uses the enable/inhibit reset path:

- D-01: Thermal-fault recovery uses BTS7960 EN/INH behavior, not SSR power-cut reset.
- D-02: Reset sequence drives both enable lines LOW, then HIGH before motion is allowed.
- D-03: Reset pulse holds enable LOW for **100 us**.
- D-04: PWM remains zero while enable is LOW and until enable returns HIGH.

## 30-minute drive protocol

1. Start in a safe open area with obstacle clearance.
2. Arm system and perform 5-minute warm-up with mixed throttle/steering.
3. Execute a 30-minute intensive run with repeated accelerations, turns, and reverse transitions.
4. Every 5 minutes record observed behavior:
   - motor response consistency
   - thermal smell/noise anomalies
   - any failsafe interventions
5. If thermal latch behavior is observed, record:
   - timestamp
   - whether EN reset sequence recovered safely
   - whether repeated events occurred

## Abort criteria

Abort immediately if any condition occurs:

- uncontrolled motion or delayed disarm
- repeated thermal shutdown with no stable recovery
- visible smoke, burning smell, or unsafe enclosure temperature
- power instability (brownout/reboot behavior)

## Required artifacts

Place artifacts in repository paths:

- Current trace bundle in `artifacts/current-trace/`
- VCP/telemetry capture logs in `artifacts/telemetry-captures/`
- Heat-sink photos and run notes referenced in UAT

Required metadata per run:

- `run_id`
- `timestamp_start` and `timestamp_end`
- `operator`
- `firmware_target` and git revision
- `battery_pack_id`
- `ambient_temp_c`
- `outcome` (pass/fail)

## Pass/fail rubric

Pass:

- No unsafe thermal event during the 30-minute intensive run.
- If a thermal latch event occurs, EN reset behavior is safe and controlled.
- Evidence set is complete and auditable (logs + metadata + photos + checklist).

Fail:

- Any abort criterion triggered.
- Missing mandatory evidence artifacts or metadata.
- Thermal behavior inconsistent with D-01..D-04 contract.

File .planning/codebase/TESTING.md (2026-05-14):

---
doc: TESTING
last_mapped: 2026-05-14
---

# Testing

## Framework & Tools

**Runner:** pytest >= 8, < 9 (declared in `requirements-dev.txt`)  
**Config:** `pytest.ini` at repo root — `testpaths = tests`

**Dev dependencies** (`requirements-dev.txt`):
- `pytest >= 8, < 9`
- `ruff >= 0.11, < 1`
- `matplotlib >= 3.9, < 4` (used for audio/spectral analysis tests)
- `PyYAML >= 6, < 7` (used for ROS2 config tests)
- All of `biba-controller/requirements.txt` (runtime deps included)

**No coverage plugin configured.** No `pytest-cov`, `pytest-asyncio`, or other pytest plugins in requirements.

## Test Structure

**Location:** All tests flat in `tests/` — no sub-directories.

**Naming:** `test_<module_name>.py` mirrors source module names:
- `tests/test_motors.py` → `biba-controller/motors/driver.py`
- `tests/test_bms_poller.py` → `biba-controller/bms/poller.py`
- `tests/test_crsf.py` → `biba-controller/crsf/`
- `tests/test_config.py` → `biba-controller/config.py`
- `tests/test_main.py` → `biba-controller/main.py`

**Test function naming:** Extremely descriptive snake_case sentences:
```
test_motor_driver_initializes_pins_and_pwm
test_bts7960_motor_driver_uses_rpwm_for_forward_motion
test_is_armed_uses_configured_channel_threshold
test_poller_returns_none_before_first_poll
```

**Test organization:** Mix of styles:
- Flat functions for single-concern tests (majority pattern)
- `class Test<Topic>` grouping for related parametric cases:
  ```python
  class TestDeadband:
      def test_small_target_zeroed(self) -> None: ...
      def test_above_deadband_not_zeroed(self) -> None: ...

  class TestAcceleration:
      def test_ramps_up_from_zero(self) -> None: ...
  ```
  Used in `tests/test_ramping.py`. Not common — most tests are top-level functions.

**Type annotations:** All test functions are annotated `-> None`.

## Test Categories

### Unit / pure-logic tests
Test isolated pure functions and classes, no I/O:
- `tests/test_ramping.py` — `SpeedRamp`, `ScalarKalmanFilter` step math
- `tests/test_current_control.py` — current limiting logic
- `tests/test_assisted_drive.py` — PID steering calculations
- `tests/test_blheli_parser.py` — melody string parsing
- `tests/test_crsf.py` — CRSF frame encoding/CRC/channel normalization
- `tests/test_stm32_link_protocol.py` — SPI protocol encoding

### Hardware-mock integration tests
Test real classes with fake hardware objects:
- `tests/test_motors.py` — `MotorDriver`, `BTS7960MotorDriver`, `DifferentialDrive` with `FakePi`
- `tests/test_bms_poller.py` — `BMSPoller` threaded polling with `FakeBMS`
- `tests/test_daly.py` — Daly BMS UART with `FakeSerial`
- `tests/test_daly_ble.py` — Daly BMS BLE with `FakeBleClient`
- `tests/test_current_sense.py` — ADS1115 reader with `FakeSMBus`
- `tests/test_lsm6ds3.py`, `tests/test_bmi160.py` — IMU drivers with `FakeBus`
- `tests/test_stm32_link_client.py` — SPI client with `FakeSpi`

### Config / environment tests
Test config loading with env var manipulation:
- `tests/test_config.py` — exhaustive default-value assertions after clearing all env vars, uses `importlib.reload(config)`

### Main controller tests
Test internal `main.py` functions via module-level monkeypatching:
- `tests/test_main.py` (5475 lines — largest test file) — tests `_is_armed`, `_is_muted`, drive mode selection, voice playback logic, trim gestures, current limiting dispatch, telemetry encoding
- `tests/test_main_voice_groups.py`, `tests/test_main_voice_audition.py`

### Voice / audio tests
- `tests/test_wav_player.py` — WAV loading, spectral cache, motor playback
- `tests/test_motor_synth.py` — motor synth PWM scheduling
- `tests/test_voice_prep_*.py` — voice asset processing pipeline (4 test files)
- `tests/test_voice_selector.py` — voice file selection policy
- `tests/test_voice_spectral_cache.py` — spectral cache read/write

### ROS2 workspace structure tests
Verify ROS2 workspace shape without running ROS:
- `tests/test_ros2_ws_skeleton.py` — package.xml presence, hook points
- `tests/test_biba_description_urdf.py` — URDF links/joints
- `tests/test_biba_description_ros2_control.py` — ros2_control XML
- `tests/test_biba_bringup_control.py`, `tests/test_biba_bringup_twist_mux.py` — launch YAML structure
- `tests/test_biba_proto_drift.py` — checks vendored proto files haven't drifted

### Script tests
- `tests/test_biba_aliases.py` — shell alias file structure
- `tests/test_setup_node.py`, `tests/test_setup_node_ros2.py` — setup scripts
- `tests/test_vcp_capture.py` — VCP telemetry capture script
- `tests/test_voice_prep_*.py` — voice asset preparation scripts

## Mocking Approach

**No `unittest.mock` / `MagicMock`** — the codebase explicitly avoids it.

**Pattern: handwritten `Fake*` classes** defined at the top of each test file, implementing only the methods actually used by the code under test:

```python
class FakePi:
    def __init__(self) -> None:
        self.mode_calls: list[tuple[int, int]] = []
        self.write_calls: list[tuple[int, int]] = []
        self._real_range = 255

    def set_mode(self, pin: int, mode: int) -> None:
        self.mode_calls.append((pin, mode))

    def write(self, pin: int, value: int) -> None:
        self.write_calls.append((pin, value))
    # ... other methods
```
`tests/test_motors.py` — `FakePi` simulates `pigpio.pi`  
`tests/test_bms_poller.py` — `FakeBMS`  
`tests/test_daly.py` — `FakeSerial`  
`tests/test_daly_ble.py` — `FakeBleClient`  
`tests/test_current_sense.py` — `FakeSMBus`  
`tests/test_lsm6ds3.py`, `tests/test_bmi160.py` — `FakeBus`  
`tests/test_stm32_link_client.py` — `FakeSpi`  
`tests/test_telemetry.py` — `FakeSerial`

**Fake classes record calls as lists** for assertion: `assert pi.mode_calls == [(18, 1), (23, 1)]`

**`monkeypatch.setattr`** for patching module attributes, config values, and class members:
```python
def test_is_armed_uses_configured_channel_threshold(monkeypatch: pytest.MonkeyPatch) -> None:
    main = importlib.import_module("main")
    monkeypatch.setattr(main.config, "CH_ARM", 2)
    monkeypatch.setattr(main.config, "ARM_THRESHOLD", 0.25)
```
Most heavily used in `tests/test_main.py` (~950 `monkeypatch` occurrences).

**`monkeypatch.delenv` / `monkeypatch.setenv`** — manipulating environment variables before `importlib.reload(config)` in `tests/test_config.py`.

**`pigpio` stub** — globally injected in `tests/conftest.py` so all tests can import biba-controller modules without the daemon:
```python
if "pigpio" not in sys.modules:
    sys.modules["pigpio"] = types.SimpleNamespace(OUTPUT=1, pi=object)
```

**Inline fake classes** — `FakeBuzzer`, `FakeSelector`, `FakeDrive` etc. defined inline inside test functions for single-use cases in `test_main.py`.

## Fixtures

### `tests/conftest.py`
Minimal — only performs path setup and pigpio stubbing:
```python
ROOT = Path(__file__).resolve().parents[1]
CONTROLLER_DIR = ROOT / "biba-controller"
sys.path.insert(0, str(CONTROLLER_DIR))

sys.modules["pigpio"] = types.SimpleNamespace(OUTPUT=1, pi=object)
```
No shared test fixtures are defined in conftest.

### Per-file fixtures
Each test file defines its own local fixtures as needed:

```python
# tests/test_config.py
@pytest.fixture
def config_module():
    return importlib.import_module("config")

# tests/test_biba_bringup_twist_mux.py
@pytest.fixture(scope="module")
def cfg() -> dict:
    return yaml.safe_load(CONFIG.read_text(encoding="utf-8"))

# tests/test_biba_description_ros2_control.py
@pytest.fixture(scope="module")
def root() -> ET.Element:
    return ET.parse(URDF_PATH).getroot()
```

### pytest built-in fixtures used
- **`monkeypatch`** — most common (950+ usages), primarily in `test_main.py` and `test_config.py`
- **`tmp_path`** — file-system tests: `test_settings_store.py`, `test_pid_tuning.py`, `test_wav_player.py` (~178 usages)

## Running Tests

```bash
# Run all tests (from repo root)
pytest

# Run all tests with verbose output
pytest -v

# Run a specific test file
pytest tests/test_motors.py

# Run a specific test
pytest tests/test_motors.py::test_motor_driver_initializes_pins_and_pwm

# Fail fast on first failure
pytest -x

# Run linter
ruff check biba-controller/

# Run tests matching a keyword
pytest -k "bms"
```

## Coverage

**No coverage enforcement configured.** No `pytest-cov` in requirements, no `[coverage]` section in `pytest.ini`.

**Observed coverage distribution:**
- `biba-controller/config.py` — thorough (exhaustive env-var defaults in `test_config.py`)
- `biba-controller/motors/` — well covered (driver, ramping, current_control, current_sense, assisted_drive all have dedicated test files)
- `biba-controller/main.py` — heavily tested via monkeypatching in `test_main.py` (5475 lines)
- `biba-controller/bms/` — covered (daly, daly_ble, poller)
- `biba-controller/crsf/` — covered (protocol, receiver)
- `biba-controller/buzzer/` — covered (wav_player, motor_synth, blheli_parser, voice_selector)
- `biba-controller/imu/` — covered (bmi160, lsm6ds3, factory)

**Gaps / low coverage areas:**
- `biba-controller/stm32_link/client.py` — hardware SPI path only partially testable without real hardware
- `biba-controller/web/` — no web tests found
- Integration/end-to-end with live pigpio daemon — excluded by design

## Common Patterns

### Float comparison
```python
assert result == pytest.approx(0.04)
assert channels[1] == pytest.approx(0.0, abs=0.001)
```
`pytest.approx` used throughout for all float assertions (~275 occurrences).

### Error testing
```python
with pytest.raises(ValueError, match="at least 22 bytes"):
    CRSFReceiver.parse_channels(b"\x00" * 21)
```

### Parametrize
```python
@pytest.mark.parametrize("pkg", CORE_PACKAGES)
def test_package_xml_exists(pkg: str) -> None: ...
```
Used in `test_ros2_ws_skeleton.py`, `test_stm32_link_protocol.py`, `test_biba_description_urdf.py`, `test_biba_proto_drift.py`.

### Real threading with deadline
For tests involving background threads (`BMSPoller`), use a real deadline loop rather than `time.sleep`:
```python
deadline = time.monotonic() + 2.0
while poller.latest_state is None and time.monotonic() < deadline:
    time.sleep(0.01)
poller.stop()
assert poller.latest_state is not None
```
`tests/test_bms_poller.py`

### Module-level import with `importlib`
For testing `main.py` (which has side effects on import), use `importlib.import_module`:
```python
main = importlib.import_module("main")
monkeypatch.setattr(main.config, "CH_ARM", 2)
```
`tests/test_main.py`, `tests/test_config.py`

### Helper factory functions
Test files define private `_make_*` functions to build test data objects:
```python
def _make_state(voltage: float = 24.0) -> BatteryState:
    return BatteryState(voltage=voltage, current=1.0, soc=80.0, ...)
```
`tests/test_bms_poller.py`, `tests/test_main.py`

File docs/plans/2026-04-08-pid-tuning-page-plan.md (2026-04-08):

# PID Tuning Page Implementation Plan

> **For Claude:** REQUIRED SUB-SKILL: Use superpowers:executing-plans to implement this plan task-by-task.

**Goal:** Add a second controller tools page that exposes live, persistent stabilized-drive tuning updates while the robot is disarmed.

**Architecture:** Extend the existing standard-library HTTP tools server with a `/pid-tuning` page and JSON API, persist tuning values in `/data/pid-tuning.json`, and let the main loop remain the only owner that applies validated pending updates by rebuilding the assisted-drive controller from a new tuning snapshot.

**Tech Stack:** Python standard library `http.server`, existing controller main loop, pytest, Docker Compose, inline HTML/CSS/JS.

---

### Task 1: Add failing config tests for persisted tuning defaults

**Files:**
- Modify: `/home/builder/biba/tests/test_config.py`
- Modify: `/home/builder/biba/biba-controller/config.py`
- Modify: `/home/builder/biba/.env.example`
- Modify: `/home/builder/biba/docker-compose.yml`

**Step 1: Write the failing test**

Add tests asserting:

- a new PID tuning settings path exists and defaults to `/data/pid-tuning.json`
- low-speed stabilization parameters used by the controller are available from config rather than only hardcoded dataclass defaults
- `.env.example` and `docker-compose.yml` expose the same settings surface

**Step 2: Run test to verify it fails**

Run: `pytest tests/test_config.py -q`
Expected: FAIL because the new persisted path and missing config defaults do not exist yet.

**Step 3: Write minimal implementation**

Add the missing config values and env/compose exposure.

**Step 4: Run test to verify it passes**

Run: `pytest tests/test_config.py -q`
Expected: PASS.

### Task 2: Add failing tests for PID tuning state and persistence helpers

**Files:**
- Create: `/home/builder/biba/tests/test_pid_tuning.py`
- Create: `/home/builder/biba/biba-controller/pid_tuning.py`

**Step 1: Write the failing test**

Add tests for:

- default snapshot construction
- JSON load and save
- invalid persisted values falling back safely
- revision tracking for pending updates
- armed-state rejection for apply requests

**Step 2: Run test to verify it fails**

Run: `pytest tests/test_pid_tuning.py -q`
Expected: FAIL because the module and behavior do not exist.

**Step 3: Write minimal implementation**

Implement:

- tuning dataclass or equivalent snapshot object
- validation helpers
- atomic JSON persistence
- a lock-protected store with current, pending, and status metadata

**Step 4: Run test to verify it passes**

Run: `pytest tests/test_pid_tuning.py -q`
Expected: PASS.

### Task 3: Add failing API tests for `/pid-tuning`

**Files:**
- Modify: `/home/builder/biba/tests/test_motor_test_api.py`
- Modify: `/home/builder/biba/biba-controller/motor_test_api.py`

**Step 1: Write the failing test**

Add tests asserting:

- `GET /pid-tuning` serves the new page
- `GET /api/pid-tuning` returns current values and armed status
- `POST /api/pid-tuning` validates payloads and returns `400` on bad input
- `POST /api/pid-tuning` returns `409` while armed
- `POST /api/pid-tuning` accepts valid disarmed updates

**Step 2: Run test to verify it fails**

Run: `pytest tests/test_motor_test_api.py -q`
Expected: FAIL because the new routes and API contract do not exist.

**Step 3: Write minimal implementation**

Extend the existing server with:

- a PID tuning page builder
- `GET /api/pid-tuning`
- `POST /api/pid-tuning`
- shared routing for both tools pages

**Step 4: Run test to verify it passes**

Run: `pytest tests/test_motor_test_api.py -q`
Expected: PASS.

### Task 4: Add failing main-loop tests for startup load and disarmed-only live apply

**Files:**
- Modify: `/home/builder/biba/tests/test_main.py`
- Modify: `/home/builder/biba/biba-controller/main.py`

**Step 1: Write the failing test**

Add tests asserting:

- the controller starts from persisted PID tuning overrides when present
- the tools server is created with access to the tuning store
- pending tuning revisions are applied only while disarmed
- applying a new revision rebuilds the assisted-drive controller from the new snapshot

**Step 2: Run test to verify it fails**

Run: `pytest tests/test_main.py -q`
Expected: FAIL because main currently has no tuning store or live apply path.

**Step 3: Write minimal implementation**

Wire startup load, tuning store ownership, and disarmed-only controller rebuild into the main loop.

**Step 4: Run test to verify it passes**

Run: `pytest tests/test_main.py -q`
Expected: PASS.

### Task 5: Add focused docs and operator guidance

**Files:**
- Modify: `/home/builder/biba/README.md`
- Modify: `/home/builder/biba/docs/deployment.md`

**Step 1: Write minimal documentation**

Document:

- `/pid-tuning` URL
- exposed parameter groups
- disarmed-only apply rule
- persistence precedence of `/data/pid-tuning.json`

**Step 2: Sanity-check docs references**

Verify no docs still describe tuning as env-only once the page exists.

### Task 6: Run focused regression coverage

**Files:**
- Test: `/home/builder/biba/tests/test_config.py`
- Test: `/home/builder/biba/tests/test_pid_tuning.py`
- Test: `/home/builder/biba/tests/test_motor_test_api.py`
- Test: `/home/builder/biba/tests/test_main.py`

**Step 1: Run focused tests**

Run: `pytest tests/test_config.py tests/test_pid_tuning.py tests/test_motor_test_api.py tests/test_main.py -q`
Expected: PASS.

**Step 2: Run the full suite**

Run: `pytest -q`
Expected: PASS.

### Task 7: Smoke-test the local tools surface

**Files:**
- No additional source changes expected

**Step 1: Run a local controller or isolated API smoke test**

Verify:

- `/motor-test` still renders
- `/pid-tuning` renders
- `GET /api/pid-tuning` returns defaults or persisted values
- `POST /api/pid-tuning` returns disarmed success and armed rejection in the appropriate test harness

**Step 2: Confirm behavior matches the contract**

Expected: one tools server, both pages reachable, no regression in existing motor test API.

### Task 8: Deploy through the normal robot update workflow

**Files:**
- No additional source changes expected

**Step 1: Push the implementation to GitHub**

Push the branch revision so GitHub Actions builds the updated controller image.

**Step 2: Wait for the relevant Actions runs**

Use `gh run watch ... --exit-status` for both the controller-image workflow and the full build workflow. Confirm the run SHA matches the pushed commit.

**Step 3: Update the robot**

Run the robot-side `bbupdate` alias through interactive SSH.

**Step 4: Verify deployment**

Confirm:

- controller container is healthy
- robot repo HEAD matches the pushed revision
- `/pid-tuning` loads from the robot
- disarmed apply works
- armed apply is rejected
- saved values survive a restart

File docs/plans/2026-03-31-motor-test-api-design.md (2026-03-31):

# Motor Test API Design

## Goal

Add a fast manual motor test control surface that lets an operator send a short left/right PWM command to the robot without touching CRSF control flow.

The immediate goal is a simple page with independent left/right frequency and duty sliders plus a duration field, backed by a robot-side HTTP endpoint that applies the requested square waves for a bounded time and then always stops both channels.

## Decision

Implement the feature inside the existing controller process using only the Python standard library.

- serve a small HTML page from the controller
- expose a JSON POST endpoint for motor test commands
- execute the test through the existing split motor PWM path already used by `MotorSynth`
- reject test requests when a previous test is still running

This avoids adding a new package, a second process, or a second transport layer.

## UI Shape

Expose a page at `/motor-test` with these controls:

- left frequency: `100..8000` Hz
- left duty: `0..100` %
- right frequency: `100..8000` Hz
- right duty: `0..100` %
- duration: configurable milliseconds, default `2000`
- send button

The page should be intentionally minimal and functional rather than a full application.

## API Contract

Expose `POST /api/motor-test` accepting JSON:

```json
{
  "left_frequency_hz": 1000,
  "left_duty_percent": 40,
  "right_frequency_hz": 1200,
  "right_duty_percent": 55,
  "duration_ms": 2000
}
```

Validation rules:

- left/right frequency: `100..8000`
- left/right duty: `0..100`
- duration: bounded positive integer, recommended `100..10000`

Response rules:

- `200` when the test is accepted and completed
- `400` for malformed or out-of-range input
- `409` when another motor test is already active
- `503` when motor test hardware is unavailable

## Runtime Integration

The controller currently constructs a `MotorSynth` instance for motor sound playback. That instance already knows the exact left and right forward and complementary pins, and already contains the low-level split-PWM application path.

The fastest and least duplicative approach is:

- add one public `MotorSynth` method for bounded manual split output
- reuse its existing pin grouping and stop behavior
- keep the HTTP layer separate from PWM mechanics

This is preferable to re-implementing pigpio pin selection in a separate module.

## Concurrency Model

Use a dedicated executor object with a lock.

Behavior:

- exactly one test may run at a time
- the HTTP handler blocks until the current test completes
- the executor always calls `off()` in a `finally` block
- a concurrent request gets `409`

The motor test path is intentionally short-lived and human-triggered, so a synchronous request is acceptable and simpler than introducing background job plumbing.

## Safety and Conflict Rules

The design intentionally stays conservative:

- no queued requests
- no indefinite playback
- no silent failure path
- guaranteed stop on exception

For the first version, the endpoint only checks whether the test executor is already active. It does not try to integrate deeply with armed/disarmed controller state, because the HTTP server lives inside the same process and the main loop already has many responsibilities. If needed later, an additional guard can reject requests while armed.

## Module Layout

Add a small dedicated module, for example `biba-controller/motor_test_api.py`, containing:

- request payload parsing and validation
- an executor class that receives a `MotorSynth`
- an HTTP handler factory
- embedded HTML for the small control page

Main runtime changes should stay narrow:

- create the motor test server only when pigpio and buzzer are available
- start it on a background thread
- shut it down in controller cleanup

## Configuration

Add environment variables for:

- enable flag
- bind host
- bind port

Reasonable defaults:

- enabled by default for now, since this is a manual engineering tool
- host `0.0.0.0`
- port `8765`

Compose should publish the port so the page is reachable from the local network.

## Testing Strategy

Add focused unit coverage for:

1. payload validation and range checks
2. concurrent-request rejection
3. duty-percent conversion
4. guaranteed `off()` on normal completion and on exception
5. HTTP page serving and JSON responses

Avoid end-to-end hardware tests in pytest. Hardware verification belongs to deployment validation on the robot.

## Non-Goals

- no persistent UI state
- no authentication layer in this first pass
- no websocket streaming
- no command queue or scheduling
- no extra standalone client application

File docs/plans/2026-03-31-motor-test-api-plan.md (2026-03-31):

# Motor Test API Implementation Plan

> **For Claude:** REQUIRED SUB-SKILL: Use superpowers:executing-plans to implement this plan task-by-task.

**Goal:** Add a robot-side HTTP motor test endpoint and simple control page that independently drive left and right PWM frequency and duty for a bounded duration.

**Architecture:** Add a small standard-library HTTP module that owns request parsing, HTML serving, and a synchronous executor built around the existing `MotorSynth` split-output path. Integrate the server into `main.py` only when pigpio-backed motor audio is available, and expose configuration through existing env-driven config and compose settings.

**Tech Stack:** Python standard library `http.server`, existing `MotorSynth`, pytest, Docker Compose.

---

### Task 1: Add failing config tests

**Files:**
- Modify: `tests/test_config.py`
- Modify: `biba-controller/config.py`

**Step 1: Write the failing test**

Add tests asserting:

- motor test API is enabled by default
- default host is `0.0.0.0`
- default port is `8765`
- environment overrides are respected

**Step 2: Run test to verify it fails**

Run: `pytest tests/test_config.py -q`
Expected: FAIL because motor test API config does not exist yet.

**Step 3: Write minimal implementation**

Add config values for enable flag, host, and port.

**Step 4: Run test to verify it passes**

Run: `pytest tests/test_config.py -q`
Expected: PASS.

### Task 2: Add failing motor test module tests

**Files:**
- Create: `tests/test_motor_test_api.py`
- Create: `biba-controller/motor_test_api.py`

**Step 1: Write the failing test**

Add tests for:

- payload validation success
- payload validation failure on out-of-range values
- duty percent conversion to `MotorSynth` duty range
- executor calls motor synth and always stops
- executor rejects concurrent activation

**Step 2: Run test to verify it fails**

Run: `pytest tests/test_motor_test_api.py -q`
Expected: FAIL because the module and behavior do not exist yet.

**Step 3: Write minimal implementation**

Implement:

- payload dataclass or equivalent parser
- executor with lock and `finally: synth.off()`
- helpers for HTML and JSON response data

**Step 4: Run test to verify it passes**

Run: `pytest tests/test_motor_test_api.py -q`
Expected: PASS.

### Task 3: Expose a public bounded split-output method on MotorSynth

**Files:**
- Modify: `biba-controller/buzzer/motor_synth.py`
- Modify: `tests/test_motor_synth.py`
- Test: `tests/test_motor_test_api.py`

**Step 1: Write the failing test**

Add a focused test proving a public method can apply independent left and right frequency/duty, wait for duration, and stop output.

**Step 2: Run test to verify it fails**

Run: `pytest tests/test_motor_synth.py tests/test_motor_test_api.py -q`
Expected: FAIL because the public method does not exist.

**Step 3: Write minimal implementation**

Add one public `MotorSynth` method that wraps the existing split apply path and duration wait.

**Step 4: Run test to verify it passes**

Run: `pytest tests/test_motor_synth.py tests/test_motor_test_api.py -q`
Expected: PASS.

### Task 4: Add failing main integration tests

**Files:**
- Modify: `tests/test_main.py`
- Modify: `biba-controller/main.py`

**Step 1: Write the failing test**

Add tests asserting:

- the HTTP server starts when pigpio-backed buzzer exists
- the server is not created in telemetry-only mode
- shutdown closes the motor test server cleanly

**Step 2: Run test to verify it fails**

Run: `pytest tests/test_main.py -q`
Expected: FAIL because `main.py` does not create or shut down the server.

**Step 3: Write minimal implementation**

Wire the server into controller startup and cleanup.

**Step 4: Run test to verify it passes**

Run: `pytest tests/test_main.py -q`
Expected: PASS.

### Task 5: Add compose exposure and document runtime usage

**Files:**
- Modify: `docker-compose.yml`
- Modify: `README.md`

**Step 1: Write the minimal docs/config change**

Document the endpoint and publish the configured port from the controller service.

**Step 2: Verify compose syntax remains valid**

Run: `docker compose config`
Expected: valid rendered compose output.

### Task 6: Run focused regression coverage

**Files:**
- Test: `tests/test_config.py`
- Test: `tests/test_motor_test_api.py`
- Test: `tests/test_motor_synth.py`
- Test: `tests/test_main.py`

**Step 1: Run focused tests**

Run: `pytest tests/test_config.py tests/test_motor_test_api.py tests/test_motor_synth.py tests/test_main.py -q`
Expected: PASS.

**Step 2: Run broader suite if focused coverage is green**

Run: `pytest -q`
Expected: PASS.

### Task 7: Deploy through the robot update workflow

**Files:**
- No additional source changes expected

**Step 1: Push the branch revision to GitHub**

Push the implementation branch so GitHub Actions builds the updated controller image.

**Step 2: Wait for the relevant Actions run**

Use `gh run watch ... --exit-status` for the image-building workflow and confirm the revision matches the pushed commit.

**Step 3: Update the robot**

Run the robot-side `bbupdate` alias through interactive SSH.

**Step 4: Verify deployment**

Confirm:

- controller container is healthy
- robot repo HEAD matches the pushed revision
- published motor test port is reachable
- `/motor-test` loads and a short test command returns success

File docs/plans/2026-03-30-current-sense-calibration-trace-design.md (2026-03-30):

# Current Sense Calibration Trace Design

## Goal

Add a controller-side calibration trace mode that records synchronized motor-control, ADS1115, and BMS telemetry samples so left and right wheel current can later be calibrated against the slower total pack current reported by the Daly BMS.

## Problem

The robot already has three relevant signal paths, but they are not currently captured together in a way that supports calibration:

- ADS1115 channels can be read quickly in the control loop.
- Left and right motor duties are known in the controller at loop time.
- Daly BMS current is available only through a slower background poller and can arrive late relative to motor activity.

The existing `Battery telemetry` INFO log is too sparse for calibration because it is rate-limited to 5 seconds and does not include ADS1115 raw values, duty outputs, or BMS sample freshness. If trace logging starts only when BMS current is nonzero, the beginning of many maneuvers will be missed because the BMS sample can lag behind wheel activity by about 1 second or more.

## Goals

1. Capture calibration data only while the platform is armed and motor activity is happening.
2. Preserve enough context to correlate fast ADS1115 samples with slower BMS samples offline.
3. Record BMS freshness explicitly so delayed BMS updates are visible in the dataset.
4. Keep the first iteration focused on logging, not online fitting or automatic current limiting.
5. Store trace samples in a machine-readable format suitable for offline statistics and regression.

## Non-Goals

- Automatic runtime fitting of current coefficients.
- Replacing the BMS current used in normal CRSF battery telemetry.
- Enabling motor current limiting during the first calibration phase.
- Inferring true physical wheel torque or RPM.
- Estimating Raspberry Pi baseline current from datasheet values alone.

## Design

### 1. Trace activation and logging gate

Introduce a dedicated calibration trace mode controlled by env configuration.

The trace should not start only when BMS current becomes nonzero. Instead, a sample is eligible for logging when all of these are true:

- the platform is armed
- calibration trace mode is enabled
- motor activity is present now, or the controller is within a short post-roll window after recent motor activity

Motor activity should be defined by any of the following:

- `abs(throttle)` above the existing deadband
- `abs(steering)` above the existing deadband
- nontrivial left or right duty output
- nonzero valid ADS1115-derived current estimate on either side

This design intentionally uses motor activity as the trigger and treats BMS as a slower reference signal. That avoids dropping the beginning of a maneuver when the BMS sample arrives late.

### 2. Trace sample format

Write one JSON object per line to a JSONL file on the persistent controller volume. Each line represents a controller-side snapshot created from one main-loop iteration.

Each sample should include:

- session identity
  - `session_id`
  - `sample_index`
- time
  - `monotonic_s`
  - `wall_time_iso`
- control state
  - `armed`
  - `raw_throttle`
  - `filtered_throttle`
  - `steering`
  - `control_active`
- motor command state
  - `requested_left`
  - `requested_right`
  - `limited_left`
  - `limited_right`
  - `trimmed_left`
  - `trimmed_right`
  - `left_duty`
  - `right_duty`
- current sense
  - `left_current_valid`
  - `right_current_valid`
  - `left_current_a`
  - `right_current_a`
  - `left_voltage_v`
  - `right_voltage_v`
  - `left_raw_adc`
  - `right_raw_adc`
  - channel metadata for left and right ADS1115 channel selection
- BMS snapshot
  - `bms_current_a`
  - `bms_voltage_v`
  - `bms_soc_pct`
  - `bms_present`
  - `bms_sample_monotonic_s`
  - `bms_age_s`
- diagnostic context
  - `mute_active`
  - `beacon_active`
  - `trim_mode_active`

The log file path should be configurable and default under `/data`, so captures survive container restarts and can be copied off the robot later.

### 3. BMS freshness tracking

The current `BMSPoller` only exposes `latest_state`. Extend it so the control loop can also obtain when that state was last updated in the controller process.

The poller should track:

- latest `BatteryState`
- monotonic timestamp of the last successful read

The main loop then computes:

$$
bms\_age\_s = now\_monotonic - bms\_sample\_monotonic
$$

This is essential because offline analysis must distinguish between:

- a fresh BMS sample that likely corresponds to the current wheel activity
- a stale BMS sample still reflecting the previous operating point

### 4. ADS1115 raw sample visibility

The current current-sense reader returns only calibrated amps and validity. For calibration trace mode, that is insufficient because the offline workflow needs the original observables.

Extend the current-sense model so the controller can log, for each wheel channel:

- raw ADC counts
- interpreted voltage
- calibrated current
- validity

The runtime may still use calibrated current for telemetry fields, but the trace file must preserve raw counts so future fitting can be repeated without recollecting data.

### 5. Post-roll behavior

Add a short configurable post-roll window, for example 2 to 3 seconds, after motor activity drops to zero.

Reason:

- the BMS sample can lag behind actual drive activity
- the user intends to hold each maneuver long enough to observe this delay
- post-roll helps capture the delayed BMS decay after wheel activity has ended

The trace sample should include whether it is inside active drive or post-roll so offline analysis can segment maneuvers cleanly.

### 6. Baseline current model

Do not subtract a hardcoded Raspberry Pi Zero 2W current value in the controller.

Instead, design the trace so offline calibration can fit a baseline term:

$$
I_{bms}(t) \approx I_{left}(t) + I_{right}(t) + I_{base}
$$

where $I_{base}$ absorbs:

- Raspberry Pi consumption
- Wi-Fi load
- ELRS receiver load
- BMS transport overhead
- other always-on electronics and conversion losses

This is more defensible than using only a spec-sheet current because the operating baseline changes with the real robot configuration.

### 7. Offline analysis target

The first phase ends with trace generation, not online fitting. The intended offline workflow is:

1. record long-enough maneuvers for idle, left-only, right-only, and both-wheel drive
2. filter trace samples by `armed`, control activity, and acceptable `bms_age_s`
3. estimate per-side offset and gain against the delayed BMS reference
4. fit a baseline term so:

$$
I_{left} + I_{right} + I_{base} \approx I_{bms}
$$

Once the trace proves stable, a later phase can decide whether to:

- compute coefficients offline and write them into env config
- or add a runtime fitting path

## Testing Strategy

Use TDD in focused slices:

1. [tests/test_bms_poller.py](tests/test_bms_poller.py)
   - latest-state timestamp is updated on successful poll
   - timestamp clears or remains unchanged on failures according to the chosen semantics

2. [tests/test_current_sense.py](tests/test_current_sense.py)
   - ADS1115 sample structure exposes raw ADC, voltage, current, and validity
   - invalid reads propagate correctly into the trace layer

3. [tests/test_main.py](tests/test_main.py)
   - trace gate requires armed state plus activity or post-roll
   - delayed BMS sample age is logged correctly
   - JSONL samples include expected fields
   - no trace is written when the feature is disabled

4. Optional focused offline test fixture
   - verify that a synthetic trace can be parsed into a DataFrame-like structure or equivalent record list if an offline helper script is introduced

## Risks and Mitigations

- Excessive log volume: mitigate with trace mode off by default and a configurable sample rate or write gate.
- Misinterpreting stale BMS as synchronous truth: mitigate by always logging `bms_age_s` and the BMS sample timestamp.
- Losing the start of a maneuver: mitigate by gating on armed motor activity, not BMS nonzero current.
- Re-fitting becoming impossible later: mitigate by logging raw ADS1115 counts, not just calibrated currents.
- Overfitting baseline from spec-sheet assumptions: mitigate by fitting `I_base` from the trace dataset instead of hardcoding Pi current.

## Deployment Notes

The feature should be off by default. Runtime config should expose:

- trace enable flag
- JSONL output path
- post-roll duration
- optional trace rate limit if needed

No robot-side manual repo edits should be required. Once implemented, deployment should go through the usual repository update flow.

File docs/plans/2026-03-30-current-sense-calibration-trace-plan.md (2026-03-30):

# Current Sense Calibration Trace Implementation Plan

> **For Claude:** REQUIRED SUB-SKILL: Use superpowers:executing-plans to implement this plan task-by-task.

**Goal:** Add a delayed-BMS-aware calibration trace mode that records synchronized controller, ADS1115, and BMS samples while the robot is armed and motor activity is present.

**Architecture:** Keep trace orchestration in [biba-controller/main.py](biba-controller/main.py): it already sees RC input, computed motor outputs, current-sense samples, and the latest BMS snapshot in one loop. Extend [biba-controller/bms/poller.py](biba-controller/bms/poller.py) to expose the timestamp of the last successful BMS update, extend the ADS1115 current-sense path to preserve raw sample details, and add a JSONL trace writer that logs only during armed activity and a short post-roll window.
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

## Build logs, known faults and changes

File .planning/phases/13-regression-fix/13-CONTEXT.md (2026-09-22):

# Phase 13: Regression Fix — Load Gate / PI Windup

**Date:** 2026-05-27
**Status:** Discussed — ready for planning

## Phase Boundary

After Phase 11 (IS-Pin Load & Stall Detection), the RPM closed-loop regulator
exhibited severe regression: wheels jerk constantly, sometimes spin in the
opposite direction, PI integral saturates at both limits (+3.0 ↔ -1.0).
Offline spectral analysis looks correct — the bug is in the **real-time
interaction** between the new load gate and the PI controller.

Phase 13 diagnoses and fixes this regression, then validates the fix with
blackbox captures and field testing.

## Root Cause Analysis

### Mechanism

```
Operator releases throttle (100% → 0%)
        ↓
Motor decelerates → generator/back-EMF effect → IS-pin current SPIKES
        ↓
Load gate fires: ratio > 1.5 & quality < 10.0 → INVALID (HIGH_LOAD)
        ↓
DR holds LAST valid RPM (~900 Hz!) — motor was at full speed
        ↓
PI sees: target=0, meas=900 → error = -900 Hz
        ↓
Integral winds NEGATIVE to saturation (-1.0) → NEGATIVE duty
        ↓
Motor REVERSES → even more IS current → gate keeps firing
        ↓
When gate eventually clears → PI overshoots due to saturated integral
        ↓
Overshoot triggers gate again → PERMANENT OSCILLATION
```

### Why Phase 11 Made It Worse

| | Before Phase 11 | After Phase 11 |
|---|---|---|
| Invalid reasons | Signal quality only (PEAK_LOW, QUALITY_LOW) | **+ DC current level (HIGH_LOAD)** |
| Max consecutive invalid | 1–2 windows (isolated) | **18+ windows (sustained)** |
| Invalid cause | Transient signal issue | **Persistent DC level (deceleration = seconds!)** |
| DR stale-hold duration | ~200 ms → PI recovers fast | **~2 seconds → PI winds to saturation** |
| PI integral range | Normal operating range | **+3.0 ↔ -1.0 (both limits)** |

**Key insight:** Before Phase 11, spectral results were invalidated only by
signal-quality issues (PEAK_LOW, QUALITY_LOW, NO_BAND). These are transient —
they affect 1–2 windows, DR holds briefly, PI recovers. After Phase 11, the
load gate adds a **DC-current-based** invalidation that persists for the
**entire deceleration period** (seconds). DR holds the last valid RPM for far
too long, PI winds up to saturation, and the system enters permanent oscillation.

Anti-stall ramp (also Phase 11) compounds the problem: it ADDS duty on top of
PI during HIGH_LOAD, making the overshoot even worse.

### Evidence

**Blackbox session_0012** (`artifacts/blackbox/session_0012.csv`):
- 72 duty oscillation events (>15% change in 40 ms)
- Duty swings: `100%→60%`, `60%→100%`, `0%→-37%` — all at **zero throttle**
- PI integral: `+3.000` ↔ `-1.000` (saturation limits)
- 0 latch resets — not a BTS7960 thermal issue

**Simulation models** (`scripts/artifacts/phase13_*.png`):
- `phase13_before_after.png` — 18× increase in consecutive invalid windows
- `phase13_root_cause_model.png` — full oscillation cycle reproduced
- `phase13_regression_analysis.png` — blackbox data + PI model

## Canonical Refs

- `firmware/src/modes/mode_standalone.c` — DMA ISR `on_adc_pair_done()`, tick function
- `firmware/src/app/rpm_spectral_estimator.c` — `biba_rpm_spectral_apply_load_gate()`
- `firmware/include/biba_config.h` — `BIBA_RPM_LOAD_*` constants
- `artifacts/blackbox/session_0012.csv` — regression evidence
- `scripts/artifacts/phase13_before_after.png` — before/after comparison model
- `scripts/artifacts/phase13_root_cause_model.png` — oscillation loop model
- `.planning/phases/11-is-pin-load-stall-detection/11-CONTEXT.md` — Phase 11 design decisions

## Locked Decisions

### D-1: Root cause is confirmed

**D-1.1:** The regression is caused by the load gate (`BIBA_FEATURE_RPM_LOAD_GATE`)
creating **sustained** (multi-second) invalid spectral windows during
deceleration, which the PI+DR chain cannot tolerate.

**D-1.2:** The anti-stall ramp (`BIBA_FEATURE_RPM_ANTI_STALL`) amplifies the
problem by adding duty on top of an already-saturated PI.

**D-1.3:** This is NOT a BTS7960 thermal latch issue (0 latch resets in
session_0012). Not an ADC capture regression. Not a CRSF/PWM driver regression.

### D-2: Fix approach — three-tier defence

**D-2.1 (Immediate — safety gate):** Add a **deceleration bypass** to the load
gate. If commanded duty magnitude is below a threshold AND the previous RPM was
above a minimum, the motor is coasting/decelerating, not stalling. In this
state, bypass the load gate (force `valid = true`).

```
IF |duty| < DECEL_DUTY_THRESH AND prev_rpm_hz > DECEL_RPM_MIN:
    → bypass load gate (motor is coasting, not stalling)
```

**D-2.2 (Robustness):** Raise `BIBA_RPM_LOAD_QUALITY_MAX` from `10.0` to `15.0`.
The current threshold of 10.0 was chosen from a 3-window test (win3, win18,
win14 in softhold dataset). In continuous driving, quality drops below 10
during normal transients (acceleration, deceleration), causing false positives.
15.0 provides headroom.

**D-2.3 (Defence in depth):** Add **PI integral reset on gate edge**. When the
load gate transitions from not-fired to fired, reset the PI integral for that
channel. This prevents the integral from winding up during sustained invalid
periods. Trade-off: brief loss of integral memory on true stall events, but
stall recovery is handled by anti-stall ramp anyway.

### D-3: Validation

**D-3.1:** After fix, blackbox captures must show:
- 0 duty oscillation events at zero throttle
- PI integral staying within normal range (not saturating)
- No negative duty at zero throttle

**D-3.2:** Field test: drive → release → verify smooth deceleration without
jerking or reverse rotation.

**D-3.3:** All 88 existing tests must continue to pass.

### D-4: What NOT to do

**D-4.1:** Do NOT remove the load gate entirely — it correctly catches true
stall events (win3, win18 in softhold). The gate logic is correct for its
intended purpose; the issue is its interaction with the PI during deceleration.

**D-4.2:** Do NOT reduce PI integral limit (3.0 → 1.0) as the primary fix. The
current limit is needed for sustained hill-climbing torque. Reducing it masks
the symptom but doesn't fix the root cause.

**D-4.3:** Do NOT switch to absolute-threshold-only gate. The ratio gate
provides valuable cross-channel context.

## Deferred Ideas

- **IS-pin current characterisation during deceleration:** Oscilloscope capture
  of IS-pin voltage during throttle release → calibrate `DECEL_DUTY_THRESH` and
  `DECEL_RPM_MIN` from real measurements. Defer to a follow-up hardware phase.
- **Goertzel execution time profiling:** GPIO-toggle measurement of
  `on_adc_pair_done` duration. The ~200 ms estimate should be verified on real
  hardware. Not blocking — the ISR latency was unchanged from Phase 10.
- **PI dt mismatch:** `BIBA_RPM_PI_DT_S = 0.104s` but effective ISR period is
  variable (200+ ms with Goertzel, ~51 ms without). Consider adaptive dt based
  on actual ISR interval. Defer to tuning phase.

## Next Steps

1. `/gsd-plan-phase 13` — create implementation plan from these decisions
2. Implement D-2.1, D-2.2, D-2.3 in firmware
3. Blackbox validation capture
4. Field smoke test

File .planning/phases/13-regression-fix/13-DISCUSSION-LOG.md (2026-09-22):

# Phase 13 Discussion Log

**Date:** 2026-05-27
**Duration:** ~2 hours

## Areas Discussed

### 1. Timing / DMA ISR execution time
**Finding:** Goertzel spectral estimation (unchanged from Phase 10) dominates
ISR time at ~275 ms per invocation (RP2040, no FPU). However, this is
unchanged from Phase 10 — the ISR double-buffering pattern (copy ADC → restart
DMA → compute) prevents data loss. Not the regression cause.

### 2. ADC buffer / data race
**Finding:** `adc_capture_start_async_pair()` unchanged from Phase 10.
Copy-then-restart pattern guarantees no race. 4-channel DMA functions added
only to PoC firmware, not standalone mode.

### 3. Latch recovery false triggers
**Finding:** With CLOSED_LOOP=0, `s_rpm_duty_left = 0.0f` → latch check
`duty > 0.05f` is always FALSE. No false triggers. 0 latch resets in
session_0012 confirm.

### 4. Include order / macro shadowing
**Finding:** `#include "biba_config.h"` added to `rpm_spectral_estimator.c`.
In `rpm_spectral_estimator.c`, the header is included before `biba_config.h`,
so header defaults win. In `mode_standalone.c`, `biba_config.h` is included
first, so its overrides apply. But values are **identical** in both — no
actual discrepancy. Fragile pattern but not the current bug.

### 5. Melody / PWM conflict
**Finding:** PWM drivers (`bts7960.c`, HAL) unchanged from Phase 10.
Melody system unchanged.

### 6. ABI struct mismatch
**Finding:** `mean_adc` added to `biba_rpm_spectral_result_t` as first field.
All code compiled together in one build → no ABI mismatch possible.

### 7. ROOT CAUSE — Load gate sustained invalid periods
**Confirmed.** Blackbox session_0012 shows 72 duty oscillation events, PI
integral at saturation limits, negative duty at zero throttle. Simulation
model shows 18× increase in consecutive invalid windows (1→18) caused by
DC-current-based load gate during deceleration.

### 8. Fix strategy
Three-tier defence agreed:
1. Deceleration bypass in load gate (if |duty| < threshold & prev_rpm > min)
2. Raise LOAD_QUALITY_MAX from 10.0 → 15.0
3. PI integral reset on gate fire edge

## Key Artifacts

- `scripts/artifacts/phase13_before_after.png` — 18× degradation visualisation
- `scripts/artifacts/phase13_root_cause_model.png` — full oscillation cycle
- `scripts/artifacts/phase13_regression_analysis.png` — blackbox + PI model
- `artifacts/blackbox/session_0012.csv` — regression evidence (72 duty swings)

## User Decisions

- CLOSED_LOOP=0 was intentional — for testing other subsystems without RPM loop
- Regression exists with CLOSED_LOOP=1 (normal operation)
- Want to fix the load gate / PI interaction, not remove the gate
- Prefer modelling/simulation approach before hardware measurements

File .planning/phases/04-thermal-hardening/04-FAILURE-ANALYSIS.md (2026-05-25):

# Phase 4 Failure Analysis: BTS7960 Thermal Risk

## Purpose

This document normalizes the community evidence chain for Phase 4 so the ESC selection and thermal-design plans can reuse it without re-reading raw dialogue.

Canonical source chain:

- [artifacts/current-trace/phase-04-community-dialogue.log](../../../artifacts/current-trace/phase-04-community-dialogue.log)
- [04-DISCUSSION-LOG.md](./04-DISCUSSION-LOG.md)
- [DIALOGUE-ANALYSIS.md](./DIALOGUE-ANALYSIS.md)
- [04-RESEARCH.md](./04-RESEARCH.md)

## Case Table

| Case | Project / Thread | Observed load | Failure timing | Thermal symptom | Root cause category | Source basis |
|---|---|---|---|---|---|---|
| 1 | BiBa field test | Dual brushed drive on 24 V system; repeated acceleration and turns | About 20-30 minutes | One side starts to lag, then driver thermal shutdown behavior appears | Thermal contact weakness + switching loss + high current spikes | Current trace, discussion log, and field notes referenced in the dialogue log |
| 2 | Arduino.ru mower thread | Two 24 V brushed motors, chain-coupled wheels, RC lawn mower | During proposed long mowing runs; concern raised before reliable field proof | BTS7960 identified as the weak link under sustained load | Current spikes from stall/start plus insufficient heat sinking | Forum thread summarized in the dialogue log |
| 3 | Arduino wheelchair thread | 24 V wheelchair motors around 14 A nominal | After repeated testing; driver failure reported after a few days | Both BTS7960 modules stopped working | Start/stall current 5-10x nominal, missing common ground, abrupt reversals | Forum thread analysis in the dialogue log |
| 4 | RadioKot / SimpleFOC discussion | Brushed motor control with NovalithIC-style driver modules | Continuous operation, especially with higher PWM frequency | Heat rise accelerates when PWM stays high | Switching losses dominate when PWM frequency is too aggressive | Community thread summary and SimpleFOC notes from the dialogue log |
| 5 | BTS7960 + MY1016Z2 field example | 24 V MY1016Z2-class motor on BTS7960 module | 20-30 minutes on a loaded drive profile | Drive weakens, module overheats, shutdown or brownout follows | High startup current plus weak thermal path from module to chassis | BTS7960 + MY1016Z2 note captured in the dialogue log |
| 6 | BTS7960 video / field example | Public BTS7960 brushed-drive example linked in the dialogue log | Continuous use case with repeated starts and stops | Thermal rise becomes the limiting factor, not nominal steady-state current | Switching losses and poor module thermal path | Linked video/example captured in the dialogue log |

## Normalized Failure Pattern

Across the cases above, the same pattern repeats:

1. Startup or stall current is much higher than steady-state current.
2. The BTS7960 module dissipates more heat than the stock thermal path can remove.
3. High PWM frequency adds switching loss on top of I2R loss.
4. After roughly 20-30 minutes of loaded drive, the module enters thermal protection or behaves as if it is collapsing thermally.
5. If the system keeps driving without a controlled cooldown or current backoff, the failure repeats.

The important conclusion for Phase 4 is that the failure is systematic. It is not just a single bad board. The combination of pulsed current, poor thermal contact, and switching losses is the recurring root cause.

## Failure Timeline

The BiBa case matches the broader community pattern:

| Time | Expected condition | Observed risk trend |
|---|---|---|
| 0 min | Cold start | High transient current, thermal margin is maximum |
| 5-10 min | Normal motion | Heat begins accumulating in the module and mounting surface |
| 15-20 min | Continuous loaded drive | Module temperature rises quickly if the thermal interface is weak |
| 20-30 min | Prolonged load | Thermal shutdown or visible drive degradation becomes likely |
| 30+ min | No mitigation | Repeated throttle loss, reset behavior, or full stop |

The 20-30 minute window is the practical warning interval that Phase 4 must design around.

## Root Cause Categories

### 1. Current spikes

Brushed motors can draw 3-10x nominal current during start, stall, or abrupt reversal. That is enough to overwhelm a driver that looks adequate on paper but has limited thermal headroom.

### 2. Thermal contact weakness

Many BTS7960 modules rely on a weak thermal path through the module PCB and a small heatsink area. If the driver is only bolted to air or plastic, heat removal is too slow for long runs.

### 3. Switching losses

Higher PWM frequency makes the module quieter, but it also increases switching loss. On an older high-current H-bridge, that can materially accelerate thermal rise.

## Reusable Comparison Matrix

| Driver | Rds(on) | Thermal headroom | Integration effort | Field-safety implication for BiBa |
|---|---|---|---|---|
| BTS7960 | About 16 mOhm per path | Marginal without real heatsinking; acceptable only with conservative current limits and lower PWM frequency | Lowest effort because the hardware already exists | Safe only as a hardened baseline; needs current backoff and good thermal contact to avoid repeated shutdowns |
| BTN8982TA | About 10 mOhm per path | Better than BTS7960; lower dissipation at the same load | Low to moderate; drop-in friendly compared with a full redesign | Strong default fallback if BTS7960 still runs hot; improves field reliability without a full board rev |
| IFX007T | About 5 mOhm per path | Highest margin in this comparison | Higher; likely needs a new board or tighter mechanical integration | Best long-run safety margin, but it is a premium path because the integration cost is higher |

## Decision Use

This analysis is intentionally conservative:

- Community anecdotes are treated as evidence of failure modes, not as controlled measurements.
- The dialogue log remains the canonical source chain for the user-facing narrative.
- The matrix is written so the selection plan can reuse it directly without reinterpretation.

## Conclusion

Phase 4 should treat the BTS7960 thermal problem as a predictable engineering limit. The usable design path is to preserve the existing drive stack only if it is paired with a proper thermal interface, lower switching loss, and current-based throttle back. If that still misses the target, BTN8982TA is the sensible fallback, and IFX007T is the premium high-margin alternative.

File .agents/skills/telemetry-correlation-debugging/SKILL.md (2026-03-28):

---
name: telemetry-correlation-debugging
description: Use when correlating BiBa transmitter-side VCP telemetry logs with robot battery telemetry logs, especially when timestamps come from different time domains, one side samples much more slowly than the other, or short current plateaus may be missed between robot log entries.
---

# Telemetry Correlation Debugging

## Overview

Use this skill to compare EdgeTX Lua VCP captures against robot-side battery telemetry logs without drawing false conclusions from timezone mismatches or unequal sampling rates.

Core principle: normalize time first, then match event shapes, then state what the coarse side cannot prove.

## Workflow

### 1. Identify the two log domains

Collect and label each source before comparing anything:

- VCP capture from `artifacts/telemetry-captures/*.log`
- Robot battery telemetry from `docker logs --timestamps ...`

For VCP logs, confirm whether lines contain:

- local wall time, such as `2026-03-28T21:53:21.752444+01:00`
- epoch seconds, such as `epoch=1774731201.752499`
- app-side values, such as `RAWI=3.00`, `RAWDIR=DIS`

For robot logs, confirm whether lines contain:

- container UTC timestamps ending in `Z`
- battery telemetry values, such as `telemetry_current_a=3.00`
- direction values, such as `telemetry_direction=DIS`

### 2. Normalize timestamps before matching

Do not compare local wall time to robot logs directly.

Use one shared time domain:

- Prefer UTC if both sources expose wall-clock timestamps.
- Prefer epoch seconds if the VCP capture includes them.

For BiBa telemetry sessions, the common pattern has been:

- local workstation log: `+01:00`
- robot shell clock: `+03:00`
- container logs: `UTC Z`

If these domains are not stated explicitly in the result, the comparison is incomplete.

### 3. Match event plateaus, not individual samples

The robot battery log is typically much coarser than the VCP stream. Treat the robot log as sparse checkpoints.

Match using event shape:

- current magnitude plateau, such as `3.00 A`
- battery direction transition, such as `IDLE -> DIS -> IDLE`
- voltage step accompanying the current event
- ordering of plateaus, such as `3.0 -> 4.9 -> 3.2 A`

Do not claim exact point-by-point equality when one side only logs every few seconds.

### 4. Separate valid conclusions from invalid ones

Valid conclusions:

- both sides saw the same sustained `DIS` event
- app-side event appears about `N` seconds after the robot-side log point
- robot-side logging frequency is too coarse to capture short peaks

Invalid conclusions:

- the robot never produced a short current plateau just because it is absent from a coarse log
- app-side latency is exactly `N` seconds from one sparse match
- the transmitter display is wrong merely because it shows more detail than the robot log

### 5. Report both the match and the gap

Every comparison should include:

- matched plateaus
- unmatched short events
- observed lag range
- confidence level based on sampling density

If the robot logs once every about 5 seconds, explicitly say that short events between samples can be missed.

## Quick Commands

Typical local VCP inspection:

```bash
grep -n 'RAWI=\|RAWDIR=' artifacts/telemetry-captures/vcp-YYYYMMDD-HHMMSS.log
```

Typical robot log extraction:

```bash
sshpass -p 'open' ssh -o StrictHostKeyChecking=no biba@192.168.2.185 \
	"docker logs --timestamps biba-biba-controller-1 2>&1 | grep 'Battery telemetry' | tail -n 120"
```

Typical narrow robot time window:

```bash
sshpass -p 'open' ssh -o StrictHostKeyChecking=no biba@192.168.2.185 \
	"docker logs --timestamps biba-biba-controller-1 2>&1 | grep '2026-03-28T20:53' | grep 'Battery telemetry'"
```

## Output Pattern

Use a compact table when presenting results:

| Event | App-side evidence | Robot-side evidence | Observed lag | Confidence |
| --- | --- | --- | --- | --- |
| `DIS 3.00 A` | VCP line and timestamp | Robot line and timestamp | Approximate | High |
| `DIS 4.90 A` | Present in VCP | Missing in robot log | Not measurable | Low because coarse robot sampling |

Then summarize:

1. what clearly matches
2. what the coarse robot log missed
3. what latency range is supportable
4. what additional logging frequency would be needed for tighter proof

## Common Mistakes

| Mistake | Why it is wrong |
| --- | --- |
| Comparing `+01:00` timestamps directly to `Z` timestamps | Time domains are different |
| Declaring a short event absent because robot logs do not show it | Coarse sampling can skip it |
| Using one matched point as an exact latency measurement | Sparse robot logs only bound the delay roughly |
| Ignoring direction fields like `DIS` and `IDLE` | Plateau ordering becomes ambiguous |

## BiBa-Specific Notes

- The active controller container may be `biba-biba-controller-1`, not `biba-controller`.
- VCP capture files can begin with one truncated line if capture starts mid-stream.
- App-side logs can show finer detail than robot logs; that is expected when the transmitter logs more frequently.

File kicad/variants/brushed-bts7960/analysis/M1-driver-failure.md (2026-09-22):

# Анализ отказа: «ключ M1 задний ход» (плата RP2040, 4× BTN7970)

Дата: 2026-09-17. Ревизия платы: EasyEDA `PCB_RP2040.json` / гербер от 2026-05-27
(`../gerber/`), схема `../easyeda/RP2040/RP2040.json`, прошивка `firmware/` (таргет `RP2040_DC_BTS7960_PWM`).

Симптом: при эксплуатации регулярно выходит из строя драйвер «заднего хода» мотора M1.

> Статус: **гипотезы по результатам разбора документации, платы и прошивки**, уточнённые
> прозвонкой (ниже). Осциллограмм VS и температуры корпуса пока нет — см. раздел «Что измерить».

## 0. Результат прозвонки (2026-09-17)

**Пробит нижний ключ U2**: вывод 1 (GND) ↔ таб/OUT (M1+) — короткое замыкание в обе стороны.
Остальные драйверы — без аномалий.

Почему это согласуется с симптомом «не работает задний ход M1»:

- Из-за `BIBA_RIGHT_MOTOR_DIR = -1` при движении робота **вперёд** ток идёт
  верхний ключ U3 → мотор → **нижний ключ U2 → GND**. Нижний ключ U2 открыт всё это время
  и проводит 100 % тока M1 (и в паузах ШИМ через нижний ключ U3 тоже). При скважности 0
  (торможение накоротко) и поворотах на месте через него идёт ток торможения и пусковой ток.
- При движении **назад** ШИМит верхний ключ U2, но нижний пробит — внутри U2 короткое замыкание
  VS–GND, срабатывает защита, мотор не крутится.

Почему именно нижний ключ U2 (уточнённый порядок причин):

1. **Постоянная нагрузка и нагрев.** Сопротивление нижнего ключа 9 мОм (25 °C) … 17.7 мОм
   (150 °C) → при 20 А это 3.6–7 Вт непрерывно, при пуске и развороте кратковременно 50–80 А.
   TO-263 без радиатора на двухслойной плате.
2. **Земля (п. 3.4).** Весь ток идёт через вывод 1 → 3 перехода Ø0.6 мм со спицами →
   нижний полигон. U2 стоит дальше всех от клеммы GND (y 12.7 мм против 73.7 мм), путь
   возврата самый длинный, переходы греются и подогревают вывод 1.
3. **Далеко от C9 и от входа питания (п. 3.1)**, торможение накоротко и рекуперация (п. 3.2).
   У левого мотора ту же роль играет нижний ключ U5, но он стоит рядом с C9 и клеммой GND.

Действия до повторного включения:

- **Не подавать питание, пока U2 не заменён** (при движении назад U2 замыкает батарею через себя).
- Проверить соседние цепи: U2 выв. 2/3 ↔ U1 выв. 18/16 ↔ GP6/GP8; R12, R11 (≈10 кОм);
  цепь R_IS (R17/R18 → GP26); VIN–GND = OL; осмотреть вывод 1 и GND-переходы U2 (перегрев).
- При замене: надёжнее подключить GND U2 и U4 (перемычка от вывода 1 к полигону/клемме),
  поставить радиатор на табы, добавить керамику и электролит у U2/U3 (п. 5).
- Прошивка: около нуля отпускать мотор накатом вместо торможения накоротко, мягче рампы,
  ограничить ток при повороте на месте. Опционально: в паузах ШИМ свободный ход через верхние
  ключи или чередование, чтобы распределить нагрев с нижнего ключа U2.

### Как проверялось

Батарея отключена, C9 разряжен, моторы отсоединены. Мультиметр в режиме прозвонки диодов,
на каждой микросхеме (ножки влево, таб справа, вывод 1 сверху):

| Щупы (+ / −) | Исправен | Пробит |
|---|---|---|
| таб / выв. 7 | 0.3–0.6 В | ~0 — верхний ключ |
| выв. 7 / таб | OL (растёт) | ~0 — верхний ключ |
| выв. 1 / таб | 0.3–0.6 В | ~0 — нижний ключ |
| таб / выв. 1 | OL | ~0 — нижний ключ |
| выв. 7 / выв. 1 | OL (растёт) | ~0 — у всех 4 сразу (общие цепи) |

## 1. Какой именно ключ

| Сигнал RP2040 | GPIO | Буфер U1 | Драйвер | Выход |
|---|---|---|---|---|
| `R_RPWM` | GP6 | 1A1→1Y1 | **U2** IN | M1+ |
| `R_REN`  | GP8 | 1A2→1Y2 | U2 INH | |
| `R_LPWM` | GP7 | 1A3→1Y3 | **U3** IN | M1− |
| `R_LEN`  | GP9 | 1A4→1Y4 | U3 INH | |

- M1 — **правый** мотор (`R_*`). По названию входа «задний ход» (`R_LPWM`) — это **U3**, но
  прозвонка показала пробой **нижнего ключа U2** (см. раздел 0): именно он проводит ток при движении
  вперёд, а при его пробое перестаёт работать движение назад.
- Распиновка прошивки (`targets/RP2040_DC_BTS7960_PWM/target.h`) совпадает с платой.
- `BIBA_RIGHT_MOTOR_DIR = -1` (`include/biba_config.h`) ⇒ при движении робота **вперёд**
  ШИМ идёт на `R_LPWM`, т.е. **U3 — самый нагруженный переключающийся ключ на плате**;
  U2 при этом статично держит нижний ключ открытым.
- Схема управления (`biba_hal_motor_rp2040.c`): 20 кГц, ШИМ на одну сторону моста,
  вторая сторона — IN=0 (открыт нижний ключ). Скважность 0 ⇒ оба нижних ключа открыты
  (динамическое торможение накоротко).

## 2. Геометрия силовой части (из гербера и PCB JSON)

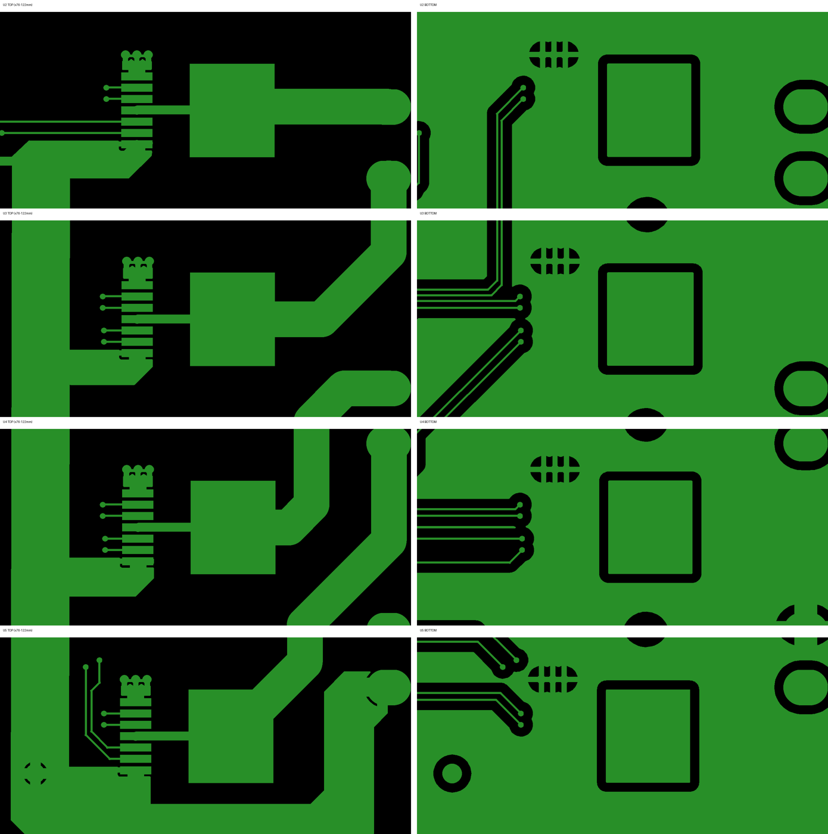
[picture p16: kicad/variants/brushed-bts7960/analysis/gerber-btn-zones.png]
Зоны драйверов U2–U5, слева TOP, справа BOTTOM


| Объект | Координаты, мм | Комментарий |
|---|---|---|
| U2 / U3 / U4 / U5 | x≈97, y = 12.7 / 37.3 / 62.1 / 86.7 | TO-263-7, таб = OUT |
| Клемма VIN (pad 5) | 119.5, 81.3 | внизу справа |
| Клемма GND (pad 6) | 119.5, 73.7 | на BOTTOM подключена 4 «спицами» ≈2–2.5 мм |
| C9 1000 мкФ (единственный) | 76.2, 90.9 | рядом с U5 |
| Шина VIN | TOP-полигон вдоль x≈77–95 | ответвления к пину 7 каждого драйвера |

- Путь по шине VIN от C9/клеммы до пина VS: U5 ≈15 мм, U4 ≈35 мм, **U3 ≈50–60 мм**, U2 ≈80 мм.
- GND каждого драйвера: пин 1 → маленький TOP-островок → **3 перехода Ø0.6 мм** → BOTTOM-полигон
  через **тепловые спицы ≈0.6 мм** (сверловка `Drill_PTH_Through.DRL`, T03 — 12 отверстий, по 3 на драйвер).
- Под табами 400 переходов Ø0.3 мм (T01) на островки OUT на BOTTOM — это сделано нормально.
- BOTTOM-полигон GND в силовой зоне разрезан сигнальными трассами IN/INH/SR/IS.
- Выходные дорожки M± — 4.0 мм (TOP, длина 18–41 мм).

## 3. Найденные проблемы (по убыванию вероятности вклада в отказ)

### 3.1. Нет керамики по питанию драйверов, DC-link далеко — **главный подозреваемый**

- Даташит BTN7970 (§6.2 Layout): керамика **≈470 нФ VS–GND у каждого прибора**.
  Шилд Infineon на BTN8982: 100 нФ VS–GND + 220 нФ OUT–VS/OUT–GND у каждого
  прибора, DC-link 1000 мкФ «с очень короткой разводкой рядом с NovalithIC»,
  требование: **пульсации VS–GND на приборе < 1 В п-п**.
- У нас: керамики нет ни у одного драйвера, единственный C9 стоит у U5.
- По номиналу тоже мало: 2× MY1016Z 24 В / **250 Вт** ≈ 21 А номинал, 50–80 А пик.
  На ШИМ 20 кГц пульсационный ток в C9 ≈ I·√(D(1−D)) ≈ **5 А RMS на мотор** (макс при
  D=0.5), ~10 А RMS на оба. У одного электролита 1000 мкФ паспортный ripple ≈ 1.5–2.5 А
  (на 20 кГц ещё ниже) — он перегревается, а его ESR ~50–100 мОм «проседает» VS под нагрузкой.
  Нужны параллельные low-ESR и керамика у каждого прибора (п.5.1/5.2), а не один большой.
- U3 — самый нагруженный ключ и одновременно самый далёкий от ёмкости и входа
  (U2 ещё дальше, но при движении вперёд он не коммутирует). Это объясняет, почему
  отказывает именно он, а не U4 (левый «вперёд», в 2 раза ближе к C9).

### 3.2. Порог перенапряжения 28–30 В при батарее 6S (25.2 В)

- BTN7970 `VOV(OFF)` = 28…30 В: драйвер выключает нижний и **открывает верхний ключ,
  игнорируя IN**. Даташит: защитные функции не рассчитаны на повторяющуюся работу.
- Абсолютный максимум VS = 45 В. TVS на входе нет.
- Источники подъёма VS: выбросы от индуктивности шины/проводов (п.3.1), рекуперация при
  сбросе газа (рампа `BIBA_RAMP_DECEL_RATE = 2.0`/с), торможение накоротко при нулевой
  скважности, токоограничение (ICL 50–98 А: при срабатывании открывается противоположный
  ключ — энергия идёт в VS). Если BMS (Daly 6S) закроет заряд — энергии некуда деться.
- Сообщество (Arduino FFB wheel, 1244625): батарея гасит рекуперацию **только пока открыт
  зарядный путь BMS**. Закрытый зарядный порт Daly 6S превращает систему в «источник без
  батареи» — VS улетает вверх точно так же, как у лабораторного БП с защитой (рекуперация
  34 В → 60+ В из Endless Sphere). Значит отказ возможен и на полном заряде, когда BMS
  закрывает заряд, а не только при «пустой» батарее.

### 3.3. Потери переключения: R_SR = 10 кОм при ШИМ 20 кГц

- Даташит (VS=13.5 В, 2 Ом): tr/tf(HS) = 0.5–2 мкс при R_SR=0; 1/2/5 мкс (мин/тип/макс)
  при 5.1 кОм; 1.6–11 мкс при 51 кОм. При 10 кОм — порядка 2–4 мкс.
- Грубая оценка: P_sw ≈ 0.5·V·I·(tr+tf)·f = 0.5·25 В·15 А·(4…8 мкс)·20 кГц ≈ **15–30 Вт**
  против ~1–2 Вт потерь проводимости. Даже при кратной ошибке оценки для TO-263 на
  2-слойке без радиатора это перегрев.
- Перегрев ⇒ отключение с защёлкой (сброс — импульс INH low; в прошивке есть
  `biba_bts7960_thermal_reset`). Даташит: частые срабатывания сокращают ресурс.
- Референсы: шилд Infineon — R_SR = **510 Ом** + конденсатор стабилизации SR;
  racecar_1_5 — **510 Ом ‖ 0.1 мкФ**.

### 3.4. Земля драйверов

- Весь ток нижнего ключа идёт через 3 перехода Ø0.6 мм и спицы 0.6 мм.
- Даташит: у BTN7970 нет раздельной силовой/логической земли, смещение между GND
  резисторов SR/IS и пином 1, а также между GND разных драйверов в мосту должно быть
  минимальным. Разрезанный нижний полигон и общий путь возврата к клемме GND это нарушают.
- Шилд Infineon: сплошной GND-слой «максимального размера», минимум 2 перехода на каждый
  конденсатор.

### 3.5. Буфер U1 SN74AHC244 питается от 5 В, вход 3.3 В

- Порог высокого уровня AHC при Vcc=5 В ≈ 0.7·Vcc = 3.5 В > 3.3 В — вход вне спецификации.
  Вместе с «прыгающей» землёй (п.3.4) возможны ложные переключения IN/INH и сквозной ток буфера.
- Входам BTN7970 хватает V_IH ≤ 2.15 В (абс. макс 5.3 В).
- Референс racecar_1_5: тот же SN74AHC244DW, но **от +3.3 В**.
- Исправление: SN74AHCT244DW (тот же корпус SOIC-20) или питать U1 от 3.3 В.
- Нет последовательных резисторов на IN/INH: в даташите и шилде Infineon — 10 кОм
  («защита при замыкании выводов МК на VS»), в racecar_1_5 — тоже 10 кОм.
- В момент старта RP2040 его GPIO — входы без подтяжек (плавают). Входы AHC244 при
  Vcc=5 В читают плавающий уровень непредсказуемо ⇒ INH/IN драйверов при включении питания
  не определены: мост может оказаться включён с произвольным IN ещё до старта прошивки.
  Решение из сообщества: 10 кОм pull-down на входах буфера (линии EN), чтобы при ресете МК
  мост гарантированно был в high-Z, а не «включён».

### 3.6. Цепь IS

- kILIS ≈ 19.5k (11…29k), IIS(lim) = 4…6.5 мА при аварии.
- R_IS = 10 кОм (R9/R11/R13/R15): АЦП (3.3 В) насыщается уже при I ≈ 6 А; при аварии
  напряжение IS стремится к VS, через 1 кОм (R17–R20) в пин RP2040 втекает до ~20 мА.
  BTN7970 это не убивает, но прошивка не видит перегрузку, а RP2040 под угрозой.
- Референсы: шилд Infineon — 1 кОм + 1 нФ, racecar_1_5 — 1 кОм + 1 нФ.
- Комментарии в `target.h` («1kΩ‖1kΩ») не соответствуют плате.

### 3.7. Прошивка

- `biba_hal_motor_audio_begin()`: сначала LPWM=0, затем инверсия канала B ⇒ до первой ноты
  на оба мотора подаётся полный «назад» (рывок на каждой мелодии, включая failsafe).
  `audio_end()` — то же на микросекунды. Нужно сначала ставить уровень `AUDIO_WRAP+1`.
- `biba_melody_player_tick_biased()` (пип заднего хода) не учитывает `BIBA_RIGHT_MOTOR_DIR`:
  правый мотор на каждом пипе получит ~90 % в обратную сторону. Сейчас выключено
  (`BIBA_FEATURE_REVERSE_PIP 0`), но включать нельзя, пока не исправлено.
- Ноль скважности = торможение накоротко нижними ключами.

## 4. Референсные схемы

| | Наша плата | Даташит BTN7970 | Шилд Infineon BTN8982TA | racecar_1_5 (BTN8962) | PGRacing GearControl v3 (BTN7970B) |
|---|---|---|---|---|---|
| Керамика VS–GND у прибора | нет | 470 нФ | 100 нФ (+220 нФ OUT–VS, OUT–GND) | нет | 470 нФ ×2 |
| Электролит | 1000 мкФ на всех, у U5 | 470 мкФ | 1000 мкФ у приборов | 220 мкФ **на каждый** | — (по BOM не видно) |
| R_SR | 10 кОм | 0…51 кОм | 510 Ом ‖ 100 нФ | 510 Ом ‖ 100 нФ | «Rsr» (подбирается) |
| R_IS | 10 кОм + 1 кОм к АЦП | 470 Ом | 1 кОм ‖ 1 нФ | 1 кОм ‖ 1 нФ | 470 Ом |
| Резисторы в IN/INH | нет | 10 кОм | 10 кОм | 10 кОм | 22 Ом |
| Буфер | AHC244 от 5 В | — | — (МК 5 В) | AHC244 от 3.3 В | 74HC126 |
| Защита входа | нет | PFET + стабилитрон | IPD90P04P4L + стабилитрон 10 В + стабилитрон 33 В 1 Вт | — | — |

Ссылки:
- [BTN7970 Data Sheet Rev 1.1](https://www.mouser.com/datasheet/2/196/BTN7970_DS_11-255465.pdf)
- [Motor Control Shield with BTN8982TA — Users Manual](https://docs.rs-online.com/91cb/0900766b81490d99.pdf),
  [репозиторий Infineon](https://github.com/Infineon/DC-Motor-Control-BTN8982TA)
- Application Note «BTN8960/62/80/82 High Current PN Half Bridge NovalithIC» (Rev 0.3, 2014) —
  гл. 3–4 и уравнение (10) для расчёта DC-link (пока не изучена)
- [flyback1228/racecar_1_5](https://github.com/flyback1228/racecar_1_5), `pcb/ACSR-RC-V2.0.pdf`, лист BTS7960.SchDoc
  (лицензии нет — только ссылка)
- [patwitt/PGRacingElectronics](https://github.com/patwitt/PGRacingElectronics), `GearControl/PCB/GearControl_v3/GearControl.csv` (BOM)
- Application Note BTN89xy [закрыта логином myInfineon](https://www.infineon.com/cms/en/product/gated-document/btn8960-62-80-82-high-current-pn-half-bridge-db3a30433fa9412f013fc8d88e3d430a/) —
  скачать вручную, в ней уравнение (10) для DC-link и правила разводки.

## 4a. Опыт сообщества (форумы, чужие репозитории)

| Источник | Что случилось | Причина / решение | К нашему пункту |
|---|---|---|---|
| [xsimulator: IBT-2 BTS7960 43A problem](https://www.xsimulator.net/community/threads/ibt-2-bts7960-43a-problem.18962/) | Горели IBT-2 на 24 В при быстрых реверсах | «Мотор отдаёт энергию обратно при быстром реверсе»; совет — питать IBT-2 не выше 20–22 В; на 12 В проблемы исчезли | 3.2 (OV 28 В, рекуперация) |
| [Arduino: BTS7960 Burnout second time](https://forum.arduino.cc/t/bts7960-burnout-second-time/849558) | Два модуля сгорели, 24 В моторы коляски | Резкие реверсы «полный вперёд → полный назад» < 1 с, нет паузы и плавного разгона; советы — пауза при смене направления, рампы, контроль IS | 3.2, 3.7 |
| [Arduino: BTS7960 Motor Driver burnout](https://forum.arduino.cc/t/bts7960-motor-driver-burnout/603767) | Модуль сгорел по VCC, 24 В / 15 А мотор | Штатный конденсатор «совершенно недостаточен» — поставить несколько 1000 мкФ у платы; рампы; ~8 кГц ШИМ; пусковой ток 100–200 А | 3.1, 3.3 |
| [dmartingarcia/scuba](https://github.com/dmartingarcia/scuba) (README) | Моторы стартовали через раз с ESP32 | SN74AHC244 на IBT-2 от 5 В не видит 3.3 В (VIH ≈ 3.5 В); питание буфера от 3.3 В решило проблему | 3.5 |
| [Hackaday: fixed burnt BTS7960](https://hackaday.io/page/399555) | Сгорел буфер 74HC244, ключи живы | Буфер обошли: МК → BTS7960 напрямую через 10 кОм (как в даташите) | 3.5 |
| [Амперка: греется провод GND логики BTS7960](https://forum.amperka.ru/threads/%D0%93%D1%80%D0%B5%D0%B5%D1%82%D1%81%D1%8F-%D0%BF%D1%80%D0%BE%D0%B2%D0%BE%D0%B4-gnd-%D0%BB%D0%BE%D0%B3%D0%B8%D0%BA%D0%B8-%D0%B4%D1%8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) | Грелся провод GND логики при моторе 6 А | Ток мотора шёл через тонкий общий GND; помогло большее сечение | 3.4 |
| [sundw2014/carADS](https://github.com/sundw2014/carADS) (`log.md`) | — | 4× BTN7970 + 74HC244; сознательно сделали прямое (без thermal relief) подключение силовых площадок к полигонам | 3.4 |
| [Endless Sphere: regen при отключённой батарее](https://endless-sphere.com/sphere/threads/did-a-stupid-regen-braking-engaged-when-battery-disconnected.119636/) | Сгорел контроллер | Рекуперация без батареи: 34 В → 60+ В | 3.2 (BMS закрыла заряд) |
| [Industrial Monitors Direct: Resolving BTS7960 direction reversal faults](https://industrialmonitordirect.com/blogs/knowledgebase/resolving-bts7960-bidirectional-motor-direction-reversal-faults) | Мотор крутится в одну сторону, под нагрузкой сам реверсирует | Плавающие L_EN/R_EN (VIH ≥ 3.0 В), сквозной ток при реверсе без dead-time (≥ 5 мкс), рекуперация через body-диоды, полоса ШИМ 1–25 кГц | 3.2, 3.3, 3.5 |
| [Arduino: BTS7960 driver burning out on FFB wheel](https://forum.arduino.cc/t/bts7960-driver-burning-out-on-arduino-ffb-wheel/1244625) | Модуль сгорел за минуты, БП уходил в защиту OC | Мотор при остановке/реверсе генерит напряжение, суммируемое с питанием; батарея его гасит, БП — нет; плюс поддельные IBT-2 | 3.2 (OV), 3.1 |
| Наш `.planning/phases/04-thermal-hardening/DIALOGUE-ANALYSIS.md` | Перегрев BTS7960 в поле | 20 кГц на старом NovalithIC — лишние потери, рекомендовано ≤ 5–10 кГц; замена на BTN8982TA/IFX007T | 3.3 |

Общий вывод сообщества: сами NovalithIC надёжны, их убивают **рекуперация/выбросы на VS при
резких реверсах и торможениях у 24 В систем**, **недостаточная ёмкость у ключей** и **перегрев**;
буфер 74HC/AHC244 — отдельная частая точка отказа и источник «странного поведения» при 3.3 В логике.

Про картинки-таблицы «RPWM=1 и LPWM=1 → BURN» (гуляют по Pinterest и форумам): на настоящих
BTN7970 оба верхних ключа открыты ⇒ оба вывода мотора на VS ⇒ ток равен нулю, это **выбег**, а не КЗ.
Реальная опасность той же картинки — сквозной ток в момент переключения без dead-time и рекуперация,
а не сама комбинация уровней; на поддельных IBT-2 поведение непредсказуемо (см. FFB wheel).

## 5. Что сделать

### Доработка текущей платы

> **Пункты 1, 2 и 7 внесены в схему KiCad** (2026-09-21), см.
> [«Внесено в схему»](#5a-внесено-в-схему) ниже. Пункт 3 (TVS на VIN) —
> **не внесён**: супрессоры поставлены на выводы моторов. На плату
> ничего из этого ещё не перенесено.

1. Керамика X7R 50 В 470 нФ – 1 мкФ (0805/1206) VS–GND у каждого драйвера, максимально
   близко к пинам 7 и 1 (TOP-полигон VIN ↔ GND-островок у пина 1).
2. Электролит 220–470 мкФ 35–50 В low-ESR рядом с парой U2/U3 (и желательно U4/U5).
3. TVS SMCJ26A (VRWM 26 В, VC ≈ 42 В) VIN–GND у клеммы.
4. U1 → SN74AHCT244DW (или питание U1 от 3.3 В).
5. R_SR (R10, R12, R14, R16) 10 кОм → 510 Ом – 2.2 кОм (проверить нагрев и помехи).
6. R_IS (R9, R11, R13, R15) 10 кОм → 1–1.5 кОм + 1 нФ; защитные диоды на входах АЦП (GP26/GP27).
7. Снаббер 100 Ом + 100 нФ X7R между OUT1–OUT2 каждого мотора (гасит звон на фронтах) и
   10 мкФ + 100 нФ у VS каждого драйвера (рекомендация сообщества, дополняет п.1).
8. Pull-down 10 кОм на входах U1 (линии EN): при ресете RP2040 мост гарантированно high-Z,
   а не «включён с неизвестным IN» (п.3.5).
9. **Тормозной чоппер** (brake chopper) VIN–GND у клеммы: компаратор (LM393) + логический
   N-MOSFET (≥ 40 В) + проволочный резистор 6.8–13 Ом / 50–100 Вт на шасси. Порог ~26.5 В,
   гистерезис ~0.5–1 В. Сбрасывает затяжную рекуперацию в тепло, когда Daly 6S закрывает
   заряд (п.3.2); TVS из п.3 гасит только короткие выбросы. Согласовать с программным лимитом
   рекуперации (п. «Прошивка» п.3): прошивка мягко срезает торможение на ~26 В, чоппер —
   последний аппаратный рубеж на 26.5 В.

### Прошивка
1. Около нуля — выбег (INH=0) вместо торможения накоротко; смена направления через паузу.
2. Мягче замедление (`BIBA_RAMP_DECEL_RATE` 2.0 → 0.5–1.0).
3. Ограничивать торможение/рекуперацию при VBAT > ~26.5 В.
4. Исправить порядок в `audio_begin`/`audio_end`; учесть `RIGHT_MOTOR_DIR` в `tick_biased`.
5. Опционально снизить частоту ШИМ (ценой слышимости) или использовать IS для ограничения тока.

### Следующая ревизия платы
- Керамика + электролит у каждого драйвера, DC-link в середине силовой шины.
- Пин 1 GND — сплошная медь без спиц, 6–10 переходов, сплошной BOTTOM-GND под силовой частью
  (сигналы увести), GND резисторов SR/IS — к пину 1 своего драйвера.
- Клеммы питания ближе к драйверам, TVS и защита от переполюсовки.
- Медь 2 oz и/или радиатор на табах.
- Рассмотреть BTN8982TA (та же распиновка TO-263-7; перед заменой сверить OV-поведение и
  абсолютные максимумы по даташиту).

## 5a. Внесено в схему

Дата: 2026-09-21. Схема `../brushed-bts7960.kicad_sch`, блок внизу листа A3.
Номиналы согласованы со статьёй [Resolving I²C bus lockup from 720 W BTS7960 PWM
motor driver](https://industrialmonitordirect.com/blogs/knowledgebase/resolving-i-c-bus-lockup-from-720w-bts7960-pwm-motor-driver)
(раздел про EMI fix) и с §5 выше.

| Поз. | Номинал | Корпус / футпринт | Цепи | Пункт | Куда ставить на плате |
|---|---|---|---|---|---|
| C10 | 470 нФ X7R 50 В | `biba:C0805` | VIN–GND | 5.1 | вплотную к пинам 7 и 1 **U2** |
| C11 | 470 нФ X7R 50 В | `biba:C0805` | VIN–GND | 5.1 | то же у **U3** |
| C12 | 470 нФ X7R 50 В | `biba:C0805` | VIN–GND | 5.1 | то же у **U4** |
| C13 | 470 нФ X7R 50 В | `biba:C0805` | VIN–GND | 5.1 | то же у **U5** |
| C14 | 1000 мкФ 50 В low-ESR | `biba:CAP-TH_BD16.0-...` | VIN–GND | 5.2 | рядом с парой **U2/U3** (C9 стоит у U5) |
| R27 + C15 | 22 Ом 5 Вт + 100 нФ 100 В плёнка | `Resistor_THT:R_Axial_Power_L25.0mm_W9.0mm_P30.48mm`, `Capacitor_THT:C_Rect_L10.0mm_W5.0mm_P5.00mm_P7.50mm` | M1+ → M1_SNUB → M1− | 5.7 | как можно ближе к клеммам мотора M1 |
| R28 + C16 | то же | то же | M2+ → M2_SNUB → M2− | 5.7 | то же для M2 |
| D1 | 1.5KE30CA | `Diode_THT:D_DO-201AE_P15.24mm_Horizontal` | M1+ – M1− | — | параллельно снабберу, у клемм мотора M1 |
| D2 | 1.5KE30CA | то же | M2+ – M2− | — | то же для M2 |

Почему так:

- **22 Ом в снаббере** — верх диапазона «10–22 Ω is a good practical starting
  point» из статьи (в §5.7 было 100 Ом). Рассеивание P ≈ C·V²·f ≈ 1.3–2.5 Вт
  от R почти не зависит, отсюда 5–10 Вт по корпусу; а пиковый ток на фронте
  25.2/22 ≈ 1.1 А против 2.5 А при 10 Ом. Точный номинал — по осциллограмме
  OUT1–OUT2 (см. §6).
- **Супрессоры поставлены на выводы моторов** (решение от 2026-09-21).
  Гасят дифференциальный выброс прямо на индуктивности обмотки, вместе со
  снаббером.
- **1.5KE30CA, а не SMCJ26A из §5.3 и не 30KPA30CA из статьи.** У 1.5KE30CA
  VC = 41.4 В при 36 А — ниже абсолютного максимума VS = 45 В у BTN7970.
  У 30KPA30CA VC ≈ 48 В, то есть выше абсолютного максимума; если ставить
  супрессор на шину, этот корпус не годится.
- **Запас по постоянному напряжению мал:** VRWM = 25.6 В при 6S Li-ion 25.2 В
  на полном заряде — 0.4 В. При полном мосте на выводах мотора и так стоит
  полное напряжение шины, так что условия те же, что и на VIN. Ток утечки
  в норме (≤5 мкА), но при переходе на 7S супрессоры придётся менять.

### Перенос на плату (2026-09-21)

Всё перечисленное разведено. **Плата выросла 124.51 × 100.33 → 180.51 ×
100.33 мм**: снабберные резисторы 5 Вт (шаг 30.5 мм, корпус 25×9 мм) на
старую плату не влезали — ближайшее свободное место было в 48 мм от клемм
мотора. Новая полоса справа от клемм держит обе снабберные группы и
альтернативный DC/DC.

Заодно добавлен **PM2 — Mean Well NSD10-48S5** (22–72 В → 5 В / 2 А) как
альтернатива PM1 SKMW30G-05. Отверстия у него **свои**, не общие с PM1:
геометрия падов у модулей одинаковая (DIP-6, ряды 20.32 мм), но назначение
выводов расходится — у SKMW30G на выводе 3 плюс выхода, у NSD10 там минус
выхода, а на выводе 4 у одного TRIM, у другого плюс выхода. Общая разводка
закоротила бы выход NSD10. Каждый модуль разведён по своему даташиту,
ставится один из двух.

Не разведено (6 связей, ratsnest в pcbnew): VIN у C10–C12 — прямая трасса к
выводу 7 режет веер сигнальных выводов 2–6, нужен обход низом; +5V и SW у
PM2; островок GND у вывода 1 U4.

### Чего эта правка не закрывает

- **§5.3 — шина VIN осталась без супрессора.** Статья держит TVS именно на
  шине («5.4 TVS Diode Across the DC Bus … inside the BTS7960 enclosure, not
  at the PSU»), и по §3.2 драйверы убивает подъём VS при рекуперации, а не
  дифференциальный выброс на обмотке: выходы моста и так зажаты body-диодами
  на VS/GND. Супрессор на выводах мотора этот сценарий не перехватывает.
  Чтобы закрыть — нужен **третий корпус 1.5KE30CA (D3) на VIN–GND у клеммы**.
- **§5.1 статьи — 10 мкФ X7R на входе.** Статья просит 100 нФ **и** 10 мкФ
  керамики у клемм драйвера; поставлено 470 нФ по §5.1 анализа и даташиту
  BTN7970. Параллельные 10 мкФ X7R 50 В остаются как дополнение.
- **§5.3 статьи — ферритовые кольца** на моторных проводах: деталь не платы,
  ставится на жгут.
- **Затяжная рекуперация при закрытом заряде Daly** — это тормозной чоппер
  (§5.9), супрессор её не лечит в любом размещении.
- Правки существующих цепей: §5.4 (U1 → AHCT244), §5.5 (R_SR), §5.6 (R_IS),
  §5.8 (pull-down на входах U1).

## 6. Что измерить, чтобы подтвердить

1. Характер отказа U3: КЗ VS–OUT / OUT–GND (мультиметр) или «не работает до перезагрузки»
   (защёлка перегрева).
2. Осциллограф на VS–GND непосредственно у пинов U3 при разгоне, торможении и смене
   направления (критерий Infineon: < 1 В п-п; не выше 28 В).
3. Температура корпуса U3 и U4 после 5 минут езды вперёд.
4. Условия отказа: полный заряд батареи? резкие торможения/развороты? длительная езда?
5. Осциллограф/логический анализатор на INH и IN каждого драйвера в момент подачи питания
   (до старта прошивки): не всплывает ли мост включённым с произвольным IN (п.3.5).

## 7. Расчёт силовых цепей по геометрии (2026-09-21)

Считано из `brushed-bts7960.kicad_pcb`, `scripts/pcb_power_check.py`.
Это **расчёт, а не измерение**: TDR и токовые клещи к плате никто не
подключал. Полевого решателя у KiCad нет, поэтому ток в полигонах не
учтён — см. оговорки в конце.

### 7.1 Волновое сопротивление — не тот критерий

Микрополосок над сплошным GND, FR-4 εr=4.5, h=1.51 мм, медь 70 мкм:

| Ширина | Z₀ |
|---|-----|
| 0.25 мм | 126 Ом |
| 0.50 мм | 106 Ом |
| 1.00 мм | 84 Ом |
| 4.00 мм | 36 Ом |

Для 50 Ом понадобилась бы дорожка ~2.7 мм. Ни одна цепь платы к этому не
приведена и не должна быть: ШИМ 20 кГц, UART, I2C — дорожки электрически
короткие, отражений нет. Волновое здесь справочное число.

### 7.2 Токонесущая способность — вот где было узко

Силовые выходы M1±/M2± разведены дорожкой **4.0 мм**. По IPC-2221
(внешний слой):

| Ток | Перегрев | Нужна ширина, 1 oz | Нужна ширина, 2 oz |
|-----|---|---|---|
| 21 А (номинал MY1016Z) | +20 °C | 13.1 мм | 6.6 мм |
| 21 А | +45 °C | 8.0 мм | **4.0 мм** |
| 50 А (пуск) | +45 °C | 26.6 мм | 13.3 мм |

Колонка 1 oz здесь для сравнения: плата делается на **2 oz**, так что
рабочий столбец — правый.

Что даёт существующая дорожка 4.0 мм:

| Перегрев | 1 oz | 2 oz |
|---|---|---|
| +10 °C | 6.5 А | 10.8 А |
| +20 °C | 8.9 А | 14.7 А |
| +45 °C | 12.7 А | 20.9 А |

На 2 oz дорожка 4 мм даёт 20.9 А при +45 °C — то есть ровно
на номинале мотора, **без запаса на пуск и разворот** (50–80 А). Держит
это нижний полигон (зоны M1±/M2± по 44–49 мм²) плюс 400 переходных под
табами — ровно для этого массив и сделан. Но запас лежит на нижнем слое,
а он разрезан сигнальными трассами (п. 3.4). На 1 oz дорожка не держала
бы и номинал — отсюда видно, насколько 2 oz здесь обязательна, а не
пожелание.

Сопротивление дорожки 4 мм длиной 40 мм на 2 oz: **2.46 мОм** — при 21 А
это 52 мВ и 1.08 Вт на дорожку (на 1 oz было бы 4.91 мОм, 103 мВ, 2.17 Вт).

### 7.3 Переходные по земле драйвера

Ствол 0.305 мм, покрытие ~25 мкм, плата 1.6 мм: ~1.15 мОм на отверстие,
три параллельно — 0.38 мОм. При 20 А это 8 мВ и 0.15 Вт.

Здесь стоит поправить п. 3.4: по чистому сопротивлению ствола три
перехода — не катастрофа. Узкое место не бочка перехода, а **тепловые
спицы 0.6 мм** на подходе к полигону: они режут сечение и мешают отводу
тепла. Посчитать спицы по файлу не получается, это к осциллографу и
термопаре (п. 6).

### 7.4 Что исправлено в этой ревизии

1. **Стекап задан явно**: медь 70 мкм (2 oz) на обоих слоях, FR-4
   1.51 мм, ENIG. Плата и так делается на 2 oz — но в файле была только
   общая толщина 1.6 мм, и вес меди оставался догадкой, из-за чего любой
   расчёт по геометрии висел в воздухе. Теперь это записано в проекте, и
   `pcb_power_check.py` берёт медь оттуда, а не из предположения.
2. **Сплошное подключение к полигону вместо тепловых спиц** у 18 силовых
   выводов: выводы 1 (GND), 7 (VS) и табы U2–U5, плюс силовые клеммы
   VIN/GND/M1±/M2±. Ошибок `starved_thermal` стало 7 → 2 (оставшиеся —
   у IC1, не силовые).
3. **Дополнительные переходные по GND у вывода 1 драйверов**: было 3 на
   драйвер, добавлено ещё по 2–3 в 1.8–2.1 мм от вывода, с дорожкой
   0.6 мм к паду. Итого переходных GND на плате 22. Это то, что п. 5
   «Следующая ревизия» просил как «6–10 переходов».

### 7.5 Чего расчёт не покрывает

- **Ток в полигонах не посчитан.** Основная часть тока идёт через
  заливку, а её распределение из геометрии дорожек не выводится.
  Нужен полевой решатель.
- Покрытие ствола перехода 25 мкм — предположение, в файле его нет.
- IPC-2221 — консервативная эмпирика для одиночной дорожки на воздухе;
  рядом с полигоном и переходными реальный перегрев ниже.
- Сопротивление тепловых спиц не учтено, а по п. 7.3 именно оно и есть
  узкое место.

Проверять по-настоящему — термопара на таб и щупы на клеммы под
нагрузкой, как в п. 6.

## Инструменты

- `scripts/easyeda_netlist.py`, `scripts/easyeda_sch2kicad.py`, `scripts/gerber_render.py`
  (нужен `pip install "pygerber<3"`).

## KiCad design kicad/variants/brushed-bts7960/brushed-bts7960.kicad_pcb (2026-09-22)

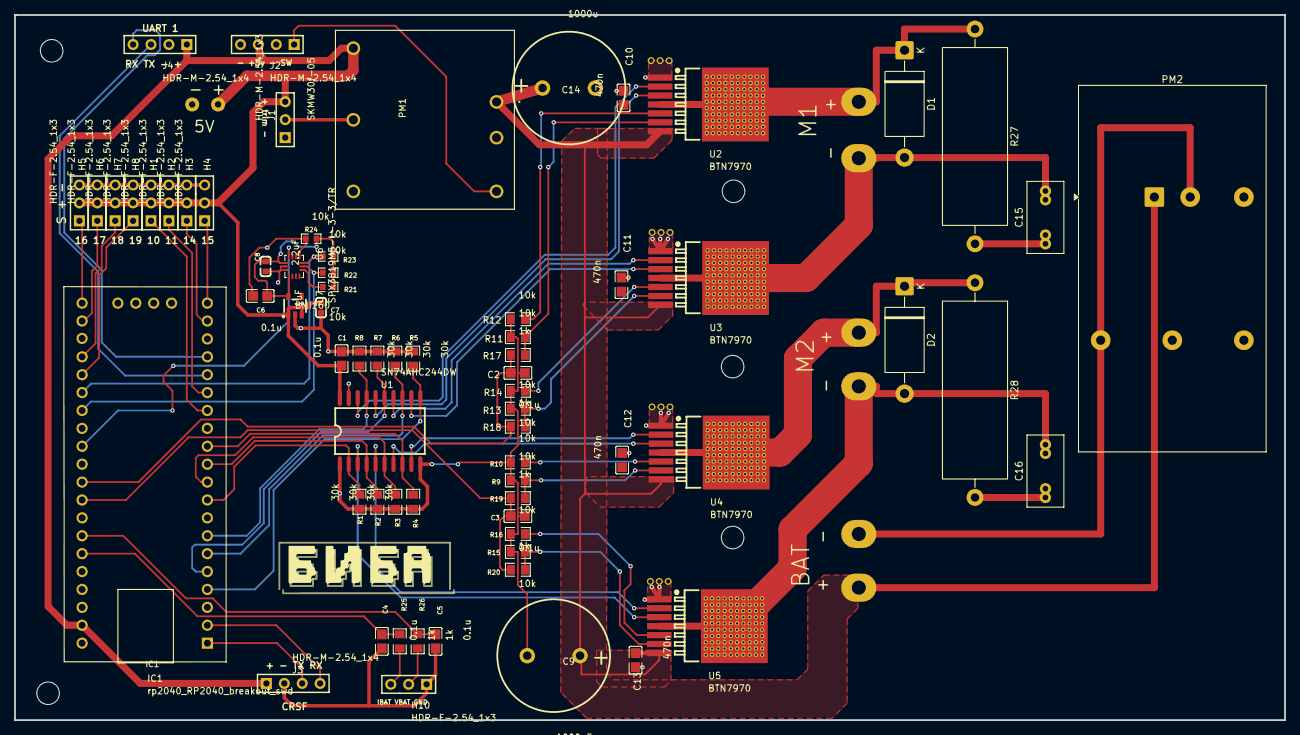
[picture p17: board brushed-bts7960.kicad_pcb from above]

Board: 2 copper layers, 180.3 x 100.1 mm, 494 parts (0 on the bottom side), 58 nets.

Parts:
C1, C2, C3, C4, C5, C6: 0.1u; C0805
C7: 1uF; C0603
C8: 2.2uF; C0603
C9: 1000uF; CAP-TH_BD16.0-P7.50-D0.8-FD-H25.0
C10, C11, C12, C13: 470n; C0805
C14: 1000u; CAP-TH_BD16.0-P7.50-D0.8-FD-H25.0
C15, C16: 100n 100V; C_Rect_L10.0mm_W5.0mm_P5.00mm_P7.50mm
D1, D2: 1.5KE30CA; D_DO-201AE_P15.24mm_Horizontal
H1, H2, H3, H4, H5, H6, H7, H8, H10: HDR-F-2.54_1x3; HDR-F-2.54_1X3
Hole_gge31981: Hole_gge31981
Hole_gge31996: Hole_gge31996
Hole_gge32011: Hole_gge32011
Hole_gge53711: Hole_gge53711
Hole_gge53741: Hole_gge53741
IC1: rp2040_RP2040_breakout_swd; RP2040-BREAKOUT_SWD
J1: HDR-M-2.54_1x3; HDR-M-2.54_1X3
J2, J3, J4: HDR-M-2.54_1x4; HDR-M-2.54_1X4
PM1: SKMW30f-05; SKMW30G-05
PM2: NSD10-48S5; Converter_DCDC_MeanWell_NSD10_THT
Pad_gge6729: Pad_gge6729
Pad_gge6765: Pad_gge6765
Pad_gge6789: Pad_gge6789
Pad_gge6813: Pad_gge6813
Pad_gge6837: Pad_gge6837
Pad_gge6861: Pad_gge6861
Pad_gge32188: Pad_gge32188
Pad_gge32224: Pad_gge32224
Pad_gge32248: Pad_gge32248
Pad_gge32347: Pad_gge32347
Pad_gge32350: Pad_gge32350
Pad_gge32353: Pad_gge32353
Pad_gge32416: Pad_gge32416
Pad_gge32419: Pad_gge32419
Pad_gge32422: Pad_gge32422
Pad_gge32482: Pad_gge32482
Pad_gge32485: Pad_gge32485
Pad_gge32488: Pad_gge32488
Pad_gge61193: Pad_gge61193
Pad_gge61325: Pad_gge61325
Pad_gge61349: Pad_gge61349
Pad_gge61511: Pad_gge61511
Pad_gge61535: Pad_gge61535
Pad_gge61559: Pad_gge61559
Pad_gge61583: Pad_gge61583
Pad_gge61607: Pad_gge61607
Pad_gge61754: Pad_gge61754
Pad_gge61757: Pad_gge61757
Pad_gge61760: Pad_gge61760
Pad_gge61763: Pad_gge61763
Pad_gge61766: Pad_gge61766
Pad_gge61769: Pad_gge61769
Pad_gge61772: Pad_gge61772
Pad_gge61775: Pad_gge61775
Pad_gge61898: Pad_gge61898
Pad_gge61901: Pad_gge61901
Pad_gge61904: Pad_gge61904
Pad_gge61907: Pad_gge61907
Pad_gge61910: Pad_gge61910
Pad_gge61913: Pad_gge61913
Pad_gge61916: Pad_gge61916
Pad_gge61919: Pad_gge61919
Pad_gge62042: Pad_gge62042
Pad_gge62045: Pad_gge62045
Pad_gge62048: Pad_gge62048
Pad_gge62051: Pad_gge62051
Pad_gge62054: Pad_gge62054
Pad_gge62057: Pad_gge62057
Pad_gge62060: Pad_gge62060
Pad_gge62063: Pad_gge62063
Pad_gge62186: Pad_gge62186
Pad_gge62189: Pad_gge62189
Pad_gge62192: Pad_gge62192
Pad_gge62195: Pad_gge62195
Pad_gge62198: Pad_gge62198
Pad_gge62201: Pad_gge62201
Pad_gge62204: Pad_gge62204
Pad_gge62207: Pad_gge62207
Pad_gge62330: Pad_gge62330
Pad_gge62333: Pad_gge62333
Pad_gge62336: Pad_gge62336
Pad_gge62339: Pad_gge62339
Pad_gge62342: Pad_gge62342
Pad_gge62345: Pad_gge62345
Pad_gge62348: Pad_gge62348
Pad_gge62351: Pad_gge62351
Pad_gge62474: Pad_gge62474
Pad_gge62477: Pad_gge62477
Pad_gge62480: Pad_gge62480
Pad_gge62483: Pad_gge62483
Pad_gge62486: Pad_gge62486
Pad_gge62489: Pad_gge62489
Pad_gge62492: Pad_gge62492
Pad_gge62495: Pad_gge62495
Pad_gge62618: Pad_gge62618
Pad_gge62621: Pad_gge62621
Pad_gge62624: Pad_gge62624
Pad_gge62627: Pad_gge62627
Pad_gge62630: Pad_gge62630
Pad_gge62633: Pad_gge62633
Pad_gge62636: Pad_gge62636
Pad_gge62639: Pad_gge62639
Pad_gge63914: Pad_gge63914
Pad_gge63917: Pad_gge63917
Pad_gge63920: Pad_gge63920
Pad_gge63923: Pad_gge63923
Pad_gge63926: Pad_gge63926
Pad_gge63929: Pad_gge63929
Pad_gge63932: Pad_gge63932
Pad_gge63935: Pad_gge63935
Pad_gge64058: Pad_gge64058
Pad_gge64061: Pad_gge64061
Pad_gge64064: Pad_gge64064
Pad_gge64067: Pad_gge64067
Pad_gge64070: Pad_gge64070
Pad_gge64073: Pad_gge64073
Pad_gge64076: Pad_gge64076
Pad_gge64079: Pad_gge64079
Pad_gge64232: Pad_gge64232
Pad_gge64235: Pad_gge64235
Pad_gge64238: Pad_gge64238
Pad_gge64241: Pad_gge64241
Pad_gge64244: Pad_gge64244
Pad_gge64247: Pad_gge64247
Pad_gge64250: Pad_gge64250
Pad_gge64253: Pad_gge64253
Pad_gge64256: Pad_gge64256
Pad_gge64259: Pad_gge64259
Pad_gge64592: Pad_gge64592
Pad_gge64595: Pad_gge64595
Pad_gge64598: Pad_gge64598
Pad_gge64601: Pad_gge64601
Pad_gge64604: Pad_gge64604
Pad_gge64607: Pad_gge64607
Pad_gge64610: Pad_gge64610
Pad_gge64613: Pad_gge64613
Pad_gge64616: Pad_gge64616
Pad_gge64619: Pad_gge64619
Pad_gge66122: Pad_gge66122
Pad_gge66125: Pad_gge66125
Pad_gge66128: Pad_gge66128
Pad_gge66131: Pad_gge66131
Pad_gge66134: Pad_gge66134
Pad_gge66137: Pad_gge66137
Pad_gge66140: Pad_gge66140
Pad_gge66143: Pad_gge66143
Pad_gge66146: Pad_gge66146
Pad_gge66149: Pad_gge66149
Pad_gge66152: Pad_gge66152
Pad_gge66155: Pad_gge66155
Pad_gge66158: Pad_gge66158
Pad_gge66161: Pad_gge66161
Pad_gge66164: Pad_gge66164
Pad_gge66167: Pad_gge66167
Pad_gge66170: Pad_gge66170
Pad_gge66173: Pad_gge66173
Pad_gge66176: Pad_gge66176
Pad_gge66179: Pad_gge66179
Pad_gge66182: Pad_gge66182
Pad_gge66185: Pad_gge66185
Pad_gge66188: Pad_gge66188
Pad_gge66191: Pad_gge66191
Pad_gge66194: Pad_gge66194
Pad_gge66197: Pad_gge66197
Pad_gge66200: Pad_gge66200
Pad_gge66203: Pad_gge66203
Pad_gge66206: Pad_gge66206
Pad_gge66209: Pad_gge66209
Pad_gge66212: Pad_gge66212
Pad_gge66215: Pad_gge66215
Pad_gge66218: Pad_gge66218
Pad_gge66221: Pad_gge66221
Pad_gge66224: Pad_gge66224
Pad_gge66227: Pad_gge66227
Pad_gge66230: Pad_gge66230
Pad_gge66233: Pad_gge66233
Pad_gge66236: Pad_gge66236
Pad_gge66239: Pad_gge66239
Pad_gge66242: Pad_gge66242
Pad_gge66245: Pad_gge66245
Pad_gge66248: Pad_gge66248
Pad_gge66251: Pad_gge66251
Pad_gge66254: Pad_gge66254
Pad_gge66257: Pad_gge66257
Pad_gge66260: Pad_gge66260
Pad_gge66263: Pad_gge66263
Pad_gge66266: Pad_gge66266
Pad_gge66269: Pad_gge66269
Pad_gge66272: Pad_gge66272
Pad_gge66275: Pad_gge66275
Pad_gge66278: Pad_gge66278
Pad_gge66281: Pad_gge66281
Pad_gge66284: Pad_gge66284
Pad_gge66287: Pad_gge66287
Pad_gge66290: Pad_gge66290
Pad_gge66293: Pad_gge66293
Pad_gge66296: Pad_gge66296
Pad_gge66299: Pad_gge66299
Pad_gge66302: Pad_gge66302
Pad_gge66305: Pad_gge66305
Pad_gge66308: Pad_gge66308
Pad_gge66311: Pad_gge66311
Pad_gge66314: Pad_gge66314
Pad_gge66317: Pad_gge66317
Pad_gge66320: Pad_gge66320
Pad_gge66323: Pad_gge66323
Pad_gge66326: Pad_gge66326
Pad_gge66329: Pad_gge66329
Pad_gge66332: Pad_gge66332
Pad_gge66335: Pad_gge66335
Pad_gge66338: Pad_gge66338
Pad_gge66341: Pad_gge66341
Pad_gge66344: Pad_gge66344
Pad_gge66347: Pad_gge66347
Pad_gge66350: Pad_gge66350
Pad_gge66353: Pad_gge66353
Pad_gge66356: Pad_gge66356
Pad_gge66359: Pad_gge66359
Pad_gge66362: Pad_gge66362
Pad_gge66365: Pad_gge66365
Pad_gge66368: Pad_gge66368
Pad_gge66371: Pad_gge66371
Pad_gge66374: Pad_gge66374
Pad_gge66377: Pad_gge66377
Pad_gge66380: Pad_gge66380
Pad_gge66383: Pad_gge66383
Pad_gge66386: Pad_gge66386
Pad_gge66389: Pad_gge66389
Pad_gge66392: Pad_gge66392
Pad_gge66395: Pad_gge66395
Pad_gge66398: Pad_gge66398
Pad_gge66401: Pad_gge66401
Pad_gge66404: Pad_gge66404
Pad_gge66407: Pad_gge66407
Pad_gge66410: Pad_gge66410
Pad_gge66413: Pad_gge66413
Pad_gge66416: Pad_gge66416
Pad_gge66419: Pad_gge66419
Pad_gge67922: Pad_gge67922
Pad_gge67925: Pad_gge67925
Pad_gge67928: Pad_gge67928
Pad_gge67931: Pad_gge67931
Pad_gge67934: Pad_gge67934
Pad_gge67937: Pad_gge67937
Pad_gge67940: Pad_gge67940
Pad_gge67943: Pad_gge67943
Pad_gge67946: Pad_gge67946
Pad_gge67949: Pad_gge67949
Pad_gge67952: Pad_gge67952
Pad_gge67955: Pad_gge67955
Pad_gge67958: Pad_gge67958
Pad_gge67961: Pad_gge67961
Pad_gge67964: Pad_gge67964
Pad_gge67967: Pad_gge67967
Pad_gge67970: Pad_gge67970
Pad_gge67973: Pad_gge67973
Pad_gge67976: Pad_gge67976
Pad_gge67979: Pad_gge67979
Pad_gge67982: Pad_gge67982
Pad_gge67985: Pad_gge67985
Pad_gge67988: Pad_gge67988
Pad_gge67991: Pad_gge67991
Pad_gge67994: Pad_gge67994
Pad_gge67997: Pad_gge67997
Pad_gge68000: Pad_gge68000
Pad_gge68003: Pad_gge68003
Pad_gge68006: Pad_gge68006
Pad_gge68009: Pad_gge68009
Pad_gge68012: Pad_gge68012
Pad_gge68015: Pad_gge68015
Pad_gge68018: Pad_gge68018
Pad_gge68021: Pad_gge68021
Pad_gge68024: Pad_gge68024
Pad_gge68027: Pad_gge68027
Pad_gge68030: Pad_gge68030
Pad_gge68033: Pad_gge68033
Pad_gge68036: Pad_gge68036
Pad_gge68039: Pad_gge68039
Pad_gge68042: Pad_gge68042
Pad_gge68045: Pad_gge68045
Pad_gge68048: Pad_gge68048
Pad_gge68051: Pad_gge68051
Pad_gge68054: Pad_gge68054
Pad_gge68057: Pad_gge68057
Pad_gge68060: Pad_gge68060
Pad_gge68063: Pad_gge68063
Pad_gge68066: Pad_gge68066
Pad_gge68069: Pad_gge68069
Pad_gge68072: Pad_gge68072
Pad_gge68075: Pad_gge68075
Pad_gge68078: Pad_gge68078
Pad_gge68081: Pad_gge68081
Pad_gge68084: Pad_gge68084
Pad_gge68087: Pad_gge68087
Pad_gge68090: Pad_gge68090
Pad_gge68093: Pad_gge68093
Pad_gge68096: Pad_gge68096
Pad_gge68099: Pad_gge68099
Pad_gge68102: Pad_gge68102
Pad_gge68105: Pad_gge68105
Pad_gge68108: Pad_gge68108
Pad_gge68111: Pad_gge68111
Pad_gge68114: Pad_gge68114
Pad_gge68117: Pad_gge68117
Pad_gge68120: Pad_gge68120
Pad_gge68123: Pad_gge68123
Pad_gge68126: Pad_gge68126
Pad_gge68129: Pad_gge68129
Pad_gge68132: Pad_gge68132
Pad_gge68135: Pad_gge68135
Pad_gge68138: Pad_gge68138
Pad_gge68141: Pad_gge68141
Pad_gge68144: Pad_gge68144
Pad_gge68147: Pad_gge68147
Pad_gge68150: Pad_gge68150
Pad_gge68153: Pad_gge68153
Pad_gge68156: Pad_gge68156
Pad_gge68159: Pad_gge68159
Pad_gge68162: Pad_gge68162
Pad_gge68165: Pad_gge68165
Pad_gge68168: Pad_gge68168
Pad_gge68171: Pad_gge68171
Pad_gge68174: Pad_gge68174
Pad_gge68177: Pad_gge68177
Pad_gge68180: Pad_gge68180
Pad_gge68183: Pad_gge68183
Pad_gge68186: Pad_gge68186
Pad_gge68189: Pad_gge68189
Pad_gge68192: Pad_gge68192
Pad_gge68195: Pad_gge68195
Pad_gge68198: Pad_gge68198
Pad_gge68201: Pad_gge68201
Pad_gge68204: Pad_gge68204
Pad_gge68207: Pad_gge68207
Pad_gge68210: Pad_gge68210
Pad_gge68213: Pad_gge68213
Pad_gge68216: Pad_gge68216
Pad_gge68219: Pad_gge68219
Pad_gge69722: Pad_gge69722
Pad_gge69725: Pad_gge69725
Pad_gge69728: Pad_gge69728
Pad_gge69731: Pad_gge69731
Pad_gge69734: Pad_gge69734
Pad_gge69737: Pad_gge69737
Pad_gge69740: Pad_gge69740
Pad_gge69743: Pad_gge69743
Pad_gge69746: Pad_gge69746
Pad_gge69749: Pad_gge69749
Pad_gge69752: Pad_gge69752
Pad_gge69755: Pad_gge69755
Pad_gge69758: Pad_gge69758
Pad_gge69761: Pad_gge69761
Pad_gge69764: Pad_gge69764
Pad_gge69767: Pad_gge69767
Pad_gge69770: Pad_gge69770
Pad_gge69773: Pad_gge69773
Pad_gge69776: Pad_gge69776
Pad_gge69779: Pad_gge69779
Pad_gge69782: Pad_gge69782
Pad_gge69785: Pad_gge69785
Pad_gge69788: Pad_gge69788
Pad_gge69791: Pad_gge69791
Pad_gge69794: Pad_gge69794
Pad_gge69797: Pad_gge69797
Pad_gge69800: Pad_gge69800
Pad_gge69803: Pad_gge69803
Pad_gge69806: Pad_gge69806
Pad_gge69809: Pad_gge69809
Pad_gge69812: Pad_gge69812
Pad_gge69815: Pad_gge69815
Pad_gge69818: Pad_gge69818
Pad_gge69821: Pad_gge69821
Pad_gge69824: Pad_gge69824
Pad_gge69827: Pad_gge69827
Pad_gge69830: Pad_gge69830
Pad_gge69833: Pad_gge69833
Pad_gge69836: Pad_gge69836
Pad_gge69839: Pad_gge69839
Pad_gge69842: Pad_gge69842
Pad_gge69845: Pad_gge69845
Pad_gge69848: Pad_gge69848
Pad_gge69851: Pad_gge69851
Pad_gge69854: Pad_gge69854
Pad_gge69857: Pad_gge69857
Pad_gge69860: Pad_gge69860
Pad_gge69863: Pad_gge69863
Pad_gge69866: Pad_gge69866
Pad_gge69869: Pad_gge69869
Pad_gge69872: Pad_gge69872
Pad_gge69875: Pad_gge69875
Pad_gge69878: Pad_gge69878
Pad_gge69881: Pad_gge69881
Pad_gge69884: Pad_gge69884
Pad_gge69887: Pad_gge69887
Pad_gge69890: Pad_gge69890
Pad_gge69893: Pad_gge69893
Pad_gge69896: Pad_gge69896
Pad_gge69899: Pad_gge69899
Pad_gge69902: Pad_gge69902
Pad_gge69905: Pad_gge69905
Pad_gge69908: Pad_gge69908
Pad_gge69911: Pad_gge69911
Pad_gge69914: Pad_gge69914
Pad_gge69917: Pad_gge69917
Pad_gge69920: Pad_gge69920
Pad_gge69923: Pad_gge69923
Pad_gge69926: Pad_gge69926
Pad_gge69929: Pad_gge69929
Pad_gge69932: Pad_gge69932
Pad_gge69935: Pad_gge69935
Pad_gge69938: Pad_gge69938
Pad_gge69941: Pad_gge69941
Pad_gge69944: Pad_gge69944
Pad_gge69947: Pad_gge69947
Pad_gge69950: Pad_gge69950
Pad_gge69953: Pad_gge69953
Pad_gge69956: Pad_gge69956
Pad_gge69959: Pad_gge69959
Pad_gge69962: Pad_gge69962
Pad_gge69965: Pad_gge69965
Pad_gge69968: Pad_gge69968
Pad_gge69971: Pad_gge69971
Pad_gge69974: Pad_gge69974
Pad_gge69977: Pad_gge69977
Pad_gge69980: Pad_gge69980
Pad_gge69983: Pad_gge69983
Pad_gge69986: Pad_gge69986
Pad_gge69989: Pad_gge69989
Pad_gge69992: Pad_gge69992
Pad_gge69995: Pad_gge69995
Pad_gge69998: Pad_gge69998
Pad_gge70001: Pad_gge70001
Pad_gge70004: Pad_gge70004
Pad_gge70007: Pad_gge70007
Pad_gge70010: Pad_gge70010
Pad_gge70013: Pad_gge70013
Pad_gge70016: Pad_gge70016
Pad_gge70019: Pad_gge70019
Pad_gge70032: Pad_gge70032
Pad_gge70234: Pad_gge70234
R1, R2, R3, R4, R5, R6, R7, R8: 30k; R0805
R9, R10, R11, R12, R13, R14, R15, R16: 10k; R0805
R17, R18, R19, R20, R25, R26: 1k; R0805
R21, R22, R23, R24: 10k; R0603
R27, R28: 22R 5W; R_Axial_Power_L25.0mm_W9.0mm_P30.48mm
U1: SN74AHC244DW; SOIC-20_L12.8-W7.5-P1.27-LS10.3-BL
U2, U3, U4, U5: BTN7970; TO-263-7_L10.2-W10.4-P1.27-LS14.4-B
U6: BMI160; LGA-14_L3.0-W2.5-P0.50-BL
U7: SPX3819M5-L-3-3/TR; SOT-23-5_L3.0-W1.7-P0.95-LS2.8-BR

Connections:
3.3V: C6.1, C8.1, R21.1, R22.2, R23.2, R24.2, U6.5, U6.8, U7.5
+5V: C1.1, C7.2, H1.2, H2.2, H3.2, H4.2, H5.2, H6.2, H7.2, H8.2, IC1.39, J1.3, J2.3, J3.1, J4.1, PM1.3, PM2.4, Pad_gge70032.27, U1.20, U7.1, U7.3
CRSF_RX: IC1.2, J3.4
CRSF_TX: IC1.1, J3.3
GND: C1.2, C2.1, C3.1, C4.2, C5.2, C6.2, C7.1, C8.2, C9.2, C10.2, C11.2, C12.2, C13.2, C14.2, H1.3, H2.3, H3.3, H4.3, H5.3, H6.3, H7.3, H8.3, H10.1, IC1.3, IC1.8, IC1.13, IC1.18, IC1.23, IC1.28, IC1.33, IC1.38, IC1.44, J1.1, J2.2, J2.4, J3.2, J4.2, PM1.2, PM1.5, PM2.2, PM2.3, Pad_gge6861.6, Pad_gge32188.7, Pad_gge32224.8, Pad_gge32248.9, Pad_gge32347.7, Pad_gge32350.8, Pad_gge32353.9, Pad_gge32416.7, Pad_gge32419.8, Pad_gge32422.9, Pad_gge32482.7, Pad_gge32485.8, Pad_gge32488.9, Pad_gge70234.28, R1.1, R2.1, R3.1, R4.1, R5.1, R6.1, R7.1, R8.1, R9.1, R10.1, R11.1, R12.1, R13.1, R14.2, R15.2, R16.1, R24.1, U1.1, U1.10, U1.19, U2.1, U3.1, U4.1, U5.1, U6.1, U6.6, U6.7, U7.2
GP10: H1.1, IC1.14
GP11: H2.1, IC1.15
GP14: H3.1, IC1.19
GP15: H4.1, IC1.20
GP16: H5.1, IC1.21
GP17: H6.1, IC1.22
GP18: H7.1, IC1.24
GP19: H8.1, IC1.25
I2C0_SCL: IC1.27, R22.1, U6.13
I2C0_SDA: IC1.26, R23.1, U6.14
IBAT: H10.3, R25.2
IC1_34: C5.1, IC1.34, R26.1
IC1_35: C4.1, IC1.35, R25.1
IMU_INT1: IC1.29, U6.4
IN1: U1.18, U2.2
IN2: U1.14, U3.2
IN3: U1.9, U4.2
IN4: U1.5, U5.2
INH1: U1.16, U2.3
INH2: U1.12, U3.3
INH3: U1.7, U4.3
INH4: U1.3, U5.3
L_IS: C3.2, IC1.32, R19.1, R20.1
L_LEN: IC1.7, R8.2, U1.17
L_LPWM: IC1.5, R7.2, U1.15
L_REN: IC1.6, R6.2, U1.13
L_RPWM: IC1.4, R5.2, U1.11
M1+: D1.1, Pad_gge6729.1, Pad_gge61193.10, Pad_gge61325.15, Pad_gge61349.16, Pad_gge61511.22, Pad_gge61535.23, Pad_gge61559.24, Pad_gge61583.25, Pad_gge61607.26, Pad_gge61754.26, Pad_gge61757.25, Pad_gge61760.24, Pad_gge61763.23, Pad_gge61766.22, Pad_gge61769.16, Pad_gge61772.15, Pad_gge61775.10, Pad_gge61898.26, Pad_gge61901.25, Pad_gge61904.24, Pad_gge61907.23, Pad_gge61910.22, Pad_gge61913.16, Pad_gge61916.15, Pad_gge61919.10, Pad_gge62042.26, Pad_gge62045.25, Pad_gge62048.24, Pad_gge62051.23, Pad_gge62054.22, Pad_gge62057.16, Pad_gge62060.15, Pad_gge62063.10, Pad_gge62186.26, Pad_gge62189.25, Pad_gge62192.24, Pad_gge62195.23, Pad_gge62198.22, Pad_gge62201.16, Pad_gge62204.15, Pad_gge62207.10, Pad_gge62330.26, Pad_gge62333.25, Pad_gge62336.24, Pad_gge62339.23, Pad_gge62342.22, Pad_gge62345.16, Pad_gge62348.15, Pad_gge62351.10, Pad_gge62474.26, Pad_gge62477.25, Pad_gge62480.24, Pad_gge62483.23, Pad_gge62486.22, Pad_gge62489.16, Pad_gge62492.15, Pad_gge62495.10, Pad_gge62618.26, Pad_gge62621.25, Pad_gge62624.24, Pad_gge62627.23, Pad_gge62630.22, Pad_gge62633.16, Pad_gge62636.15, Pad_gge62639.10, Pad_gge63914.26, Pad_gge63917.26, Pad_gge63920.26, Pad_gge63923.26, Pad_gge63926.26, Pad_gge63929.26, Pad_gge63932.26, Pad_gge63935.26, Pad_gge64058.26, Pad_gge64061.26, Pad_gge64064.26, Pad_gge64067.26, Pad_gge64070.26, Pad_gge64073.26, Pad_gge64076.26, Pad_gge64079.26, Pad_gge64232.26, Pad_gge64235.26, Pad_gge64238.10, Pad_gge64241.15, Pad_gge64244.16, Pad_gge64247.22, Pad_gge64250.23, Pad_gge64253.24, Pad_gge64256.25, Pad_gge64259.26, Pad_gge64592.26, Pad_gge64595.26, Pad_gge64598.10, Pad_gge64601.15, Pad_gge64604.16, Pad_gge64607.22, Pad_gge64610.23, Pad_gge64613.24, Pad_gge64616.25, Pad_gge64619.26, R27.1, U2.4, U2.8
M1-: C15.2, D1.2, Pad_gge6765.2, Pad_gge66122.26, Pad_gge66125.25, Pad_gge66128.24, Pad_gge66131.23, Pad_gge66134.22, Pad_gge66137.16, Pad_gge66140.15, Pad_gge66143.10, Pad_gge66146.26, Pad_gge66149.26, Pad_gge66152.26, Pad_gge66155.25, Pad_gge66158.24, Pad_gge66161.23, Pad_gge66164.22, Pad_gge66167.16, Pad_gge66170.15, Pad_gge66173.10, Pad_gge66176.26, Pad_gge66179.26, Pad_gge66182.26, Pad_gge66185.26, Pad_gge66188.26, Pad_gge66191.26, Pad_gge66194.26, Pad_gge66197.26, Pad_gge66200.26, Pad_gge66203.26, Pad_gge66206.26, Pad_gge66209.26, Pad_gge66212.26, Pad_gge66215.26, Pad_gge66218.26, Pad_gge66221.26, Pad_gge66224.26, Pad_gge66227.26, Pad_gge66230.10, Pad_gge66233.15, Pad_gge66236.16, Pad_gge66239.22, Pad_gge66242.23, Pad_gge66245.24, Pad_gge66248.25, Pad_gge66251.26, Pad_gge66254.10, Pad_gge66257.15, Pad_gge66260.16, Pad_gge66263.22, Pad_gge66266.23, Pad_gge66269.24, Pad_gge66272.25, Pad_gge66275.26, Pad_gge66278.10, Pad_gge66281.15, Pad_gge66284.16, Pad_gge66287.22, Pad_gge66290.23, Pad_gge66293.24, Pad_gge66296.25, Pad_gge66299.26, Pad_gge66302.10, Pad_gge66305.15, Pad_gge66308.16, Pad_gge66311.22, Pad_gge66314.23, Pad_gge66317.24, Pad_gge66320.25, Pad_gge66323.26, Pad_gge66326.10, Pad_gge66329.15, Pad_gge66332.16, Pad_gge66335.22, Pad_gge66338.23, Pad_gge66341.24, Pad_gge66344.25, Pad_gge66347.26, Pad_gge66350.10, Pad_gge66353.15, Pad_gge66356.16, Pad_gge66359.22, Pad_gge66362.23, Pad_gge66365.24, Pad_gge66368.25, Pad_gge66371.26, Pad_gge66374.10, Pad_gge66377.15, Pad_gge66380.16, Pad_gge66383.22, Pad_gge66386.23, Pad_gge66389.24, Pad_gge66392.25, Pad_gge66395.26, Pad_gge66398.26, Pad_gge66401.25, Pad_gge66404.24, Pad_gge66407.23, Pad_gge66410.22, Pad_gge66413.16, Pad_gge66416.15, Pad_gge66419.10, U3.4, U3.8
M1_SNUB: C15.1, R27.2
M2+: D2.1, Pad_gge6789.3, Pad_gge67922.26, Pad_gge67925.25, Pad_gge67928.24, Pad_gge67931.23, Pad_gge67934.22, Pad_gge67937.16, Pad_gge67940.15, Pad_gge67943.10, Pad_gge67946.26, Pad_gge67949.26, Pad_gge67952.26, Pad_gge67955.25, Pad_gge67958.24, Pad_gge67961.23, Pad_gge67964.22, Pad_gge67967.16, Pad_gge67970.15, Pad_gge67973.10, Pad_gge67976.26, Pad_gge67979.26, Pad_gge67982.26, Pad_gge67985.26, Pad_gge67988.26, Pad_gge67991.26, Pad_gge67994.26, Pad_gge67997.26, Pad_gge68000.26, Pad_gge68003.26, Pad_gge68006.26, Pad_gge68009.26, Pad_gge68012.26, Pad_gge68015.26, Pad_gge68018.26, Pad_gge68021.26, Pad_gge68024.26, Pad_gge68027.26, Pad_gge68030.10, Pad_gge68033.15, Pad_gge68036.16, Pad_gge68039.22, Pad_gge68042.23, Pad_gge68045.24, Pad_gge68048.25, Pad_gge68051.26, Pad_gge68054.10, Pad_gge68057.15, Pad_gge68060.16, Pad_gge68063.22, Pad_gge68066.23, Pad_gge68069.24, Pad_gge68072.25, Pad_gge68075.26, Pad_gge68078.10, Pad_gge68081.15, Pad_gge68084.16, Pad_gge68087.22, Pad_gge68090.23, Pad_gge68093.24, Pad_gge68096.25, Pad_gge68099.26, Pad_gge68102.10, Pad_gge68105.15, Pad_gge68108.16, Pad_gge68111.22, Pad_gge68114.23, Pad_gge68117.24, Pad_gge68120.25, Pad_gge68123.26, Pad_gge68126.10, Pad_gge68129.15, Pad_gge68132.16, Pad_gge68135.22, Pad_gge68138.23, Pad_gge68141.24, Pad_gge68144.25, Pad_gge68147.26, Pad_gge68150.10, Pad_gge68153.15, Pad_gge68156.16, Pad_gge68159.22, Pad_gge68162.23, Pad_gge68165.24, Pad_gge68168.25, Pad_gge68171.26, Pad_gge68174.10, Pad_gge68177.15, Pad_gge68180.16, Pad_gge68183.22, Pad_gge68186.23, Pad_gge68189.24, Pad_gge68192.25, Pad_gge68195.26, Pad_gge68198.26, Pad_gge68201.25, Pad_gge68204.24, Pad_gge68207.23, Pad_gge68210.22, Pad_gge68213.16, Pad_gge68216.15, Pad_gge68219.10, R28.1, U4.4, U4.8
M2-: C16.2, D2.2, Pad_gge6813.4, Pad_gge69722.26, Pad_gge69725.25, Pad_gge69728.24, Pad_gge69731.23, Pad_gge69734.22, Pad_gge69737.16, Pad_gge69740.15, Pad_gge69743.10, Pad_gge69746.26, Pad_gge69749.26, Pad_gge69752.26, Pad_gge69755.25, Pad_gge69758.24, Pad_gge69761.23, Pad_gge69764.22, Pad_gge69767.16, Pad_gge69770.15, Pad_gge69773.10, Pad_gge69776.26, Pad_gge69779.26, Pad_gge69782.26, Pad_gge69785.26, Pad_gge69788.26, Pad_gge69791.26, Pad_gge69794.26, Pad_gge69797.26, Pad_gge69800.26, Pad_gge69803.26, Pad_gge69806.26, Pad_gge69809.26, Pad_gge69812.26, Pad_gge69815.26, Pad_gge69818.26, Pad_gge69821.26, Pad_gge69824.26, Pad_gge69827.26, Pad_gge69830.10, Pad_gge69833.15, Pad_gge69836.16, Pad_gge69839.22, Pad_gge69842.23, Pad_gge69845.24, Pad_gge69848.25, Pad_gge69851.26, Pad_gge69854.10, Pad_gge69857.15, Pad_gge69860.16, Pad_gge69863.22, Pad_gge69866.23, Pad_gge69869.24, Pad_gge69872.25, Pad_gge69875.26, Pad_gge69878.10, Pad_gge69881.15, Pad_gge69884.16, Pad_gge69887.22, Pad_gge69890.23, Pad_gge69893.24, Pad_gge69896.25, Pad_gge69899.26, Pad_gge69902.10, Pad_gge69905.15, Pad_gge69908.16, Pad_gge69911.22, Pad_gge69914.23, Pad_gge69917.24, Pad_gge69920.25, Pad_gge69923.26, Pad_gge69926.10, Pad_gge69929.15, Pad_gge69932.16, Pad_gge69935.22, Pad_gge69938.23, Pad_gge69941.24, Pad_gge69944.25, Pad_gge69947.26, Pad_gge69950.10, Pad_gge69953.15, Pad_gge69956.16, Pad_gge69959.22, Pad_gge69962.23, Pad_gge69965.24, Pad_gge69968.25, Pad_gge69971.26, Pad_gge69974.10, Pad_gge69977.15, Pad_gge69980.16, Pad_gge69983.22, Pad_gge69986.23, Pad_gge69989.24, Pad_gge69992.25, Pad_gge69995.26, Pad_gge69998.26, Pad_gge70001.25, Pad_gge70004.24, Pad_gge70007.23, Pad_gge70010.22, Pad_gge70013.16, Pad_gge70016.15, Pad_gge70019.10, U5.4, U5.8
M2_SNUB: C16.1, R28.2
PM1_4: J1.2, PM1.4
R_IS: C2.2, IC1.31, R17.1, R18.1
R_LEN: IC1.12, R4.2, U1.8
R_LPWM: IC1.10, R3.2, U1.6
R_REN: IC1.11, R2.2, U1.4
R_RPWM: IC1.9, R1.2, U1.2
SW: J2.1, PM1.6, PM2.6
U2_5: R12.2, U2.5
U2_6: R11.2, R17.2, U2.6
U3_5: R14.1, U3.5
U3_6: R13.2, R18.2, U3.6
U4_5: R10.2, U4.5
U4_6: R9.2, R19.2, U4.6
U5_5: R16.2, U5.5
U5_6: R15.1, R20.2, U5.6
U6_12: R21.2, U6.12
UART1_RX: IC1.17, J4.4
UART1_TX: IC1.16, J4.3
VBAT: H10.2, R26.2
VIN: C9.1, C10.1, C11.1, C12.1, C13.1, C14.1, PM1.1, PM2.1, Pad_gge6837.5, U2.7, U3.7, U4.7, U5.7

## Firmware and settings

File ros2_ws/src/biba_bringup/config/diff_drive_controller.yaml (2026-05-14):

# diff_drive_controller for BiBa composition C.
#
# Subscribes to /cmd_vel (output of twist_mux) and writes velocity
# commands to wheel_left_joint / wheel_right_joint via the
# biba_hardware_stm32 SystemInterface. Publishes /odom from the
# integrated joint states (open-loop, since the wheels have no
# encoders — see read() in biba_stm32_system.cpp).

controller_manager:
  ros__parameters:
    update_rate: 50  # Hz; matches firmware control loop budget
    use_sim_time: false

    joint_state_broadcaster:
      type: joint_state_broadcaster/JointStateBroadcaster

    diff_drive_controller:
      type: diff_drive_controller/DiffDriveController

diff_drive_controller:
  ros__parameters:
    left_wheel_names: ["left_wheel_joint"]
    right_wheel_names: ["right_wheel_joint"]

    # Geometry — must match biba_description/urdf/biba.urdf.xacro.
    wheel_separation: 0.30
    wheel_radius: 0.0425

    # Multipliers stay at 1.0 until field-calibrated.
    wheel_separation_multiplier: 1.0
    left_wheel_radius_multiplier: 1.0
    right_wheel_radius_multiplier: 1.0

    publish_rate: 50.0
    odom_frame_id: odom
    base_frame_id: base_link
    pose_covariance_diagonal: [0.001, 0.001, 1e6, 1e6, 1e6, 0.03]
    twist_covariance_diagonal: [0.001, 0.001, 1e6, 1e6, 1e6, 0.03]

    open_loop: true             # no encoders; integrate commanded twist
    enable_odom_tf: true
    cmd_vel_timeout: 0.5        # seconds; halt if /cmd_vel goes silent
    publish_limited_velocity: true
    use_stamped_vel: false

    # Linear / angular limits (rough field defaults; tighten on hardware).
    linear:
      x:
        has_velocity_limits: true
        has_acceleration_limits: true
        max_velocity: 1.5         # m/s
        max_acceleration: 2.0     # m/s^2
    angular:
      z:
        has_velocity_limits: true
        has_acceleration_limits: true
        max_velocity: 3.0         # rad/s
        max_acceleration: 4.0     # rad/s^2

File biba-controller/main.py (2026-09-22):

"""Main runtime loop for the BiBa wheeled platform controller."""

from __future__ import annotations

import inspect
import json
import logging
import math
import os
import signal
import threading
import time
from datetime import datetime, timezone
from pathlib import Path
from types import FrameType

import config
import pigpio
import yaml
from bms.daly import BatteryState, DalyBMS, DalyBMSBle
from bms.poller import BMSPoller
from buzzer.beacon import BeaconManager
from buzzer.melodies import FUN_PLAYLIST
from buzzer.motor_synth import MotorSynth
from buzzer.voice_selector import VoiceSelector
from crsf.receiver import CRSFReceiver
from crsf.telemetry import CRSFTelemetry, build_biba_system_metrics
from imu import IMUSample, NullIMUReader
from imu.factory import open_imu_reader
from motor_test_api import MotorTestExecutor, create_motor_test_server
from motors.assisted_drive import (
    AssistedDriveConfig,
    AssistedDriveController,
    AssistedDriveResult,
    DriveMode,
)
from motors.current_control import (
    MotorCurrentSample,
    MotorLimitConfig,
    MotorLimitResult,
    apply_motor_limits,
)
from motors.current_sense import (
    MotorCurrentCalibration,
    NullMotorCurrentReader,
    open_ads1115_current_reader,
)
from motors.driver import BTS7960MotorDriver, DifferentialDrive, MotorDriver
from motors.ramping import ScalarKalmanFilter
from pid_tuning import PidTuningSnapshot, PidTuningStore, load_pid_tuning
from settings_store import MotorTrimStore
from system_stats import SystemStats

LOGGER = logging.getLogger("biba-controller")
RUNNING = True
_BATTERY_TELEMETRY_LOG_INTERVAL_S = 5.0
_IMU_ASSIST_ERROR_LOG_INTERVAL_S = 5.0
_NEUTRAL_ASSIST_ACTIVITY_LOG_INTERVAL_S = 0.5
_BATTERY_DIRECTION_MASK = 0b00011
_BATTERY_STATUS_ARMED = 0b00100
_BATTERY_STATUS_MUTED = 0b01000
_BATTERY_STATUS_BEACON = 0b10000
_BATTERY_STATUS_TRIM_MODE = 0b100000
_TRIM_GESTURE_CHANNEL_COUNT = 4
_TRIM_GESTURE_HIGH_THRESHOLD = 0.9
_ARM_SOUND_HOLD_S = 0.250
_DISARM_SOUND_SETTLE_S = 0.120
_SYNTH_EVENT_NAMES = {
    "startup": "startup",
    "arm": "arm",
    "disarm": "disarm",
    "connected": "connected",
    "disconnected": "disconnected",
    "failsafe": "failsafe",
    "low_voltage": "low_voltage",
}


def _clamp_motor_trim(trim: float) -> float:
    return max(-config.MOTOR_TRIM_MAX_EFFECT, min(config.MOTOR_TRIM_MAX_EFFECT, trim))


def wheel_rpm_to_mps(rpm_hz: float) -> float:
    """Convert IS-signal ZC frequency (Hz) to wheel linear speed (m/s).

    Returns 0.0 for rpm_hz <= 0 (no signal / motor stopped) or when the
    configured GEAR_RATIO is zero (avoids ZeroDivisionError if env is bad).
    """
    if rpm_hz <= 0.0:
        return 0.0
    if config.GEAR_RATIO == 0.0:
        return 0.0
    return (2.0 * math.pi * rpm_hz * config.WHEEL_RADIUS_M) / config.GEAR_RATIO


class _NullDrive:
    def mix_and_ramp(self, throttle: float, steering: float, dt: float = 0.02) -> tuple[float, float]:
        del throttle, steering, dt
        return (0.0, 0.0)

    def apply_output(
        self,
        left_duty: float,
        right_duty: float,
        *,
        throttle: float = 0.0,
        steering: float = 0.0,
        dt: float = 0.02,
    ) -> tuple[float, float]:
        del left_duty, right_duty, throttle, steering, dt
        return (0.0, 0.0)

    def drive(self, throttle: float, steering: float, dt: float = 0.02) -> tuple[float, float]:
        del throttle, steering, dt
        return (0.0, 0.0)

    def stop(self) -> None:
        pass

    def check_failsafe(self, last_frame_time: float) -> bool:
        del last_frame_time
        return False

    def emergency_stop(self) -> None:
        pass


class _NullBuzzer:
    def off(self) -> None:
        pass

    def startup_tone(self) -> None:
        pass

    def shutdown_tone(self) -> None:
        pass

    def connected_tone(self) -> None:
        pass

    def disconnected_tone(self) -> None:
        pass

    def arm_tone(self) -> None:
        pass

    def disarm_tone(self) -> None:
        pass

    def failsafe_tone(self) -> None:
        pass

    def sos_beacon(self) -> None:
        pass

    def low_voltage_alarm(self) -> None:
        pass

    def play_named(self, name: str) -> None:
        del name

    def play_named_async(self, name: str) -> None:
        del name

    def set_control_active(self, active: bool) -> None:
        del active

    def play_blheli(self, melody_str: str, tempo_bpm: int = 120) -> None:
        del melody_str, tempo_bpm

    def play_wav(self, path: str) -> None:
        del path

    def play_spectral(self, path: str) -> None:
        del path

    def play_wav_async(self, path: str) -> None:
        del path

    def play_spectral_async(self, path: str) -> None:
        del path


def _play_grouped_voice(
    selector: VoiceSelector,
    event: str,
    voices: list[str],
    buzzer,
) -> bool:
    if config.SOUND_MODE == "synth":
        synth_name = _resolve_synth_sound_name(event)
        if synth_name is None:
            return False
        buzzer.play_named(synth_name)
        return True

    path = selector.choose(event, voices)
    if path is None:
        return False
    player = _resolve_voice_player(buzzer, async_mode=False)
    if player is None:
        return False
    player(path)
    return True


def _play_grouped_voice_async(
    selector: VoiceSelector,
    event: str,
    voices: list[str],
    buzzer,
) -> bool:
    if config.SOUND_MODE == "synth":
        synth_name = _resolve_synth_sound_name(event)
        if synth_name is None:
            return False

        buzzer.play_named(synth_name)
        return True

    path = selector.choose(event, voices)
    if path is None:
        return False

    player = _resolve_voice_player(buzzer, async_mode=True)
    if player is not None:
        player(path)
        return True

    player = _resolve_voice_player(buzzer, async_mode=False)
    if player is None:
        return False
    threading.Thread(target=player, args=(path,), daemon=True).start()
    return True


def _resolve_synth_sound_name(event: str) -> str | None:
    if event == "startup":
        return config.STARTUP_MELODY or _SYNTH_EVENT_NAMES[event]
    return _SYNTH_EVENT_NAMES.get(event)


def _resolve_voice_player(buzzer, *, async_mode: bool):
    if config.SOUND_MODE == "voice":
        return getattr(buzzer, "play_wav_async" if async_mode else "play_wav", None)
    if config.SOUND_MODE == "spectral_voice":
        return getattr(buzzer, "play_spectral_async" if async_mode else "play_spectral", None)
    return None


def _play_grouped_voice_if_allowed(
    selector: VoiceSelector,
    event: str,
    voices: list[str],
    buzzer,
    *,
    mute_active: bool,
    allow_when_muted: bool = False,
) -> bool:
    if mute_active and not allow_when_muted:
        return False
    return _play_grouped_voice(selector, event, voices, buzzer)


def _play_grouped_voice_async_if_allowed(
    selector: VoiceSelector,
    event: str,
    voices: list[str],
    buzzer,
    *,
    mute_active: bool,
    allow_when_muted: bool = False,
) -> bool:
    if mute_active and not allow_when_muted:
        return False
    return _play_grouped_voice_async(selector, event, voices, buzzer)


def _play_buzzer_method_async(buzzer, method_name: str) -> None:
    if config.SOUND_MODE == "synth":
        getattr(buzzer, method_name)()
        return

    player = getattr(buzzer, f"{method_name}_async", None)
    if player is not None:
        player()
        return

    player = getattr(buzzer, method_name)
    threading.Thread(target=player, daemon=True).start()


def _play_buzzer_method_async_if_allowed(
    buzzer,
    method_name: str,
    *,
    mute_active: bool,
    allow_when_muted: bool = False,
) -> bool:
    if mute_active and not allow_when_muted:
        return False
    _play_buzzer_method_async(buzzer, method_name)
    return True


def _play_named_async_if_allowed(
    buzzer,
    name: str,
    *,
    mute_active: bool,
    allow_when_muted: bool = False,
) -> bool:
    if mute_active and not allow_when_muted:
        return False
    if config.SOUND_MODE == "synth":
        buzzer.play_named(name)
        return True
    buzzer.play_named_async(name)
    return True


def _play_named_if_allowed(
    buzzer,
    name: str,
    *,
    mute_active: bool,
    allow_when_muted: bool = False,
) -> bool:
    if mute_active and not allow_when_muted:
        return False
    buzzer.play_named(name)
    return True


def _replay_current_audio_state_after_unmute(
    voice_selector: VoiceSelector,
    buzzer,
    *,
    connected: bool,
    armed: bool,
) -> bool:
    if armed:
        if (config.SOUND_MODE == "synth" or config.ARM_VOICE_ENABLED) and _play_grouped_voice_async_if_allowed(
            voice_selector,
            "arm",
            config.ARM_VOICES,
            buzzer,
            mute_active=False,
        ):
            return True
        return _play_buzzer_method_async_if_allowed(
            buzzer,
            "arm_tone",
            mute_active=False,
        )

    if connected:
        if _play_grouped_voice_async_if_allowed(
            voice_selector,
            "connected",
            config.CONNECTED_VOICES,
            buzzer,
            mute_active=False,
        ):
            return True
        return _play_buzzer_method_async_if_allowed(
            buzzer,
            "connected_tone",
            mute_active=False,
        )

    return False


def _create_synth_pins() -> tuple[list[int], list[int]]:
    left_pwm_pins, left_comp_pins, right_pwm_pins, right_comp_pins = _create_synth_motor_groups()
    return left_pwm_pins + right_pwm_pins, left_comp_pins + right_comp_pins


def _create_synth_motor_groups() -> tuple[list[int], list[int], list[int], list[int]]:
    left_pwm_pins: list[int] = []
    left_comp_pins: list[int] = []
    right_pwm_pins: list[int] = []
    right_comp_pins: list[int] = []
    if config.LEFT_MOTOR_ENABLED:
        if bool(config.MOTOR1_INVERTED):
            left_pwm_pins.append(config.LEFT_MOTOR_LPWM)
            left_comp_pins.append(config.LEFT_MOTOR_RPWM)
        else:
            left_pwm_pins.append(config.LEFT_MOTOR_RPWM)
            left_comp_pins.append(config.LEFT_MOTOR_LPWM)
    if config.RIGHT_MOTOR_ENABLED:
        if bool(config.MOTOR2_INVERTED):
            right_pwm_pins.append(config.RIGHT_MOTOR_LPWM)
            right_comp_pins.append(config.RIGHT_MOTOR_RPWM)
        else:
            right_pwm_pins.append(config.RIGHT_MOTOR_RPWM)
            right_comp_pins.append(config.RIGHT_MOTOR_LPWM)
    return left_pwm_pins, left_comp_pins, right_pwm_pins, right_comp_pins


def _create_buzzer(pi: pigpio.pi):
    synth_pwm_pins, synth_comp_pins = _create_synth_pins()
    left_pwm_pins, left_comp_pins, right_pwm_pins, right_comp_pins = _create_synth_motor_groups()
    return MotorSynth(
        pi,
        synth_pwm_pins,
        comp_pins=synth_comp_pins,
        pwm_mode=config.BTS7960_PWM_MODE,
        left_pwm_pins=left_pwm_pins,
        left_comp_pins=left_comp_pins,
        right_pwm_pins=right_pwm_pins,
        right_comp_pins=right_comp_pins,
    )


def _create_test_motor_synth(buzzer, pwm_mode: str):
    normalized_mode = str(pwm_mode).strip().upper()
    current_mode = str(getattr(buzzer, "_pwm_mode", normalized_mode)).upper()
    if normalized_mode == current_mode:
        return buzzer

    if not all(hasattr(buzzer, attr) for attr in ("pi", "pwm_pins", "duty_cycle")):
        return None

    left_pwm_pins = list(getattr(buzzer, "left_pwm_pins", []))
    right_pwm_pins = list(getattr(buzzer, "right_pwm_pins", []))
    left_comp_pins = list(getattr(buzzer, "_raw_left_comp_pins", getattr(buzzer, "left_comp_pins", [])))
    right_comp_pins = list(getattr(buzzer, "_raw_right_comp_pins", getattr(buzzer, "right_comp_pins", [])))
    comp_pins = list(dict.fromkeys(left_comp_pins + right_comp_pins))
    if not comp_pins:
        comp_pins = list(getattr(buzzer, "comp_pins", []))

    return MotorSynth(
        buzzer.pi,
        list(getattr(buzzer, "pwm_pins", [])),
        duty_cycle=getattr(buzzer, "duty_cycle", 50_000),
        comp_pins=comp_pins,
        pwm_mode=normalized_mode,
        left_pwm_pins=left_pwm_pins,
        left_comp_pins=left_comp_pins,
        right_pwm_pins=right_pwm_pins,
        right_comp_pins=right_comp_pins,
    )


def _create_motor_test_executor(buzzer, drive):
    if not config.MOTOR_TEST_API_ENABLED:
        return None
    if not hasattr(buzzer, "play_manual_split_pwm"):
        return None
    before_run = getattr(drive, "emergency_stop", None)
    return MotorTestExecutor(
        buzzer,
        before_run=before_run,
        synth_factory=lambda pwm_mode: _create_test_motor_synth(buzzer, pwm_mode),
    )


def _motor_test_active(executor) -> bool:
    return bool(executor is not None and getattr(executor, "is_active", False))


def _supports_kwarg(callable_obj, argument_name: str) -> bool:
    parameters = inspect.signature(callable_obj).parameters.values()
    if argument_name in inspect.signature(callable_obj).parameters:
        return True
    return any(parameter.kind == inspect.Parameter.VAR_KEYWORD for parameter in parameters)


def _supports_positional_argument(callable_obj) -> bool:
    parameters = inspect.signature(callable_obj).parameters.values()
    return any(
        parameter.kind
        in (
            inspect.Parameter.POSITIONAL_ONLY,
            inspect.Parameter.POSITIONAL_OR_KEYWORD,
            inspect.Parameter.VAR_POSITIONAL,
        )
        for parameter in parameters
    )


def _create_motor_test_server(
    executor,
    *,
    pid_tuning_store: PidTuningStore | None = None,
    motor_trim_store: MotorTrimStore | None = None,
):
    if executor is None:
        return None
    return create_motor_test_server(
        executor,
        host=config.MOTOR_TEST_API_HOST,
        port=config.MOTOR_TEST_API_PORT,
        pid_tuning_store=pid_tuning_store,
        motor_trim_store=motor_trim_store,
    )


def _start_motor_test_server(server) -> threading.Thread | None:
    if server is None:
        return None
    thread = threading.Thread(target=server.serve_forever, daemon=True)
    thread.start()
    LOGGER.info(
        "Settings UI listening on http://%s:%s/settings (legacy /motor-test, /pid-tuning)",
        config.MOTOR_TEST_API_HOST,
        getattr(server, "server_port", config.MOTOR_TEST_API_PORT),
    )
    return thread


def _shutdown_motor_test_server(server) -> None:
    if server is None:
        return
    server.shutdown()
    server.server_close()


def _load_voice_audition_candidates(path: str) -> list[str]:
    if not path:
        raise ValueError("VOICE_AUDITION_MANIFEST must be set when audition mode is enabled")
    data = yaml.safe_load(Path(path).read_text(encoding="utf-8")) or {}
    candidates = data.get("candidates", [])
    if not isinstance(candidates, list) or not all(isinstance(item, str) and item.strip() for item in candidates):
        raise ValueError("audition manifest candidates must be a non-empty list of strings")
    return [item.strip() for item in candidates]


def _run_voice_audition_mode() -> int:
    pi = _connect_pigpio()
    if not pi.connected:
        LOGGER.warning("Could not connect to pigpio daemon, voice audition mode cannot start")
        return 1

    buzzer = _create_buzzer(pi)
    try:
        for candidate in _load_voice_audition_candidates(config.VOICE_AUDITION_MANIFEST):
            buzzer.play_spectral(candidate)
    finally:
        buzzer.off()
        pi.stop()

    return 0


def _setup_logging() -> None:
    logging.basicConfig(
        level=getattr(logging, config.LOG_LEVEL.upper(), logging.INFO),
        format="%(asctime)s %(levelname)s %(name)s: %(message)s",
    )


def _signal_handler(signum: int, frame: FrameType | None) -> None:
    del signum, frame
    global RUNNING
    RUNNING = False


def _is_armed(channels: list[float]) -> bool:
    if len(channels) <= config.CH_ARM:
        return False
    return channels[config.CH_ARM] > config.ARM_THRESHOLD


def _is_muted(channels: list[float]) -> bool:
    return _get_channel(channels, config.CH_MUTE) > config.ARM_THRESHOLD


def _get_channel(channels: list[float], index: int) -> float:
    if index >= len(channels):
        return 0.0
    return channels[index]


def _trim_gesture_active(channels: list[float]) -> bool:
    for index in range(_TRIM_GESTURE_CHANNEL_COUNT):
        if _get_channel(channels, index) < _TRIM_GESTURE_HIGH_THRESHOLD:
            return False
    return True


def _live_motor_trim_from_channels(channels: list[float]) -> float:
    return _clamp_motor_trim(_get_channel(channels, config.CH_TRIM) * config.MOTOR_TRIM_MAX_EFFECT)


def _get_speed_mode_scale(channels: list[float]) -> float:
    selector = _get_channel(channels, config.CH_SPEED_MODE)
    if selector < config.SPEED_MODE_LOW_THRESHOLD:
        return config.SPEED_MODE_SLOW_SCALE
    if selector > config.SPEED_MODE_HIGH_THRESHOLD:
        return config.SPEED_MODE_FAST_SCALE
    return config.SPEED_MODE_MEDIUM_SCALE


def _get_drive_mode(channels: list[float]) -> str:
    if len(channels) <= config.CH_DRIVE_MODE:
        return DriveMode.MANUAL.value
    selector = _get_channel(channels, config.CH_DRIVE_MODE)
    if selector < config.DRIVE_MODE_LOW_THRESHOLD:
        return DriveMode.MANUAL.value
    return DriveMode.STABILIZED.value


def _scale_drive_inputs_for_speed_mode(throttle: float, steering: float, speed_mode_scale: float) -> tuple[float, float]:
    mixed_left = max(-1.0, min(1.0, throttle + steering))
    mixed_right = max(-1.0, min(1.0, throttle - steering))
    scaled_left = mixed_left * speed_mode_scale
    scaled_right = mixed_right * speed_mode_scale
    return (scaled_left + scaled_right) / 2.0, (scaled_left - scaled_right) / 2.0


def _limit_drive_output_for_speed_mode(throttle: float, steering: float, speed_mode_scale: float) -> tuple[float, float]:
    limited_throttle = max(-speed_mode_scale, min(speed_mode_scale, throttle))
    steering_limit = max(0.0, speed_mode_scale - abs(limited_throttle))
    limited_steering = max(-steering_limit, min(steering_limit, steering))
    return limited_throttle, limited_steering


def _battery_is_low(state: BatteryState) -> bool:
    if state.cells and state.min_cell > 0:
        return state.min_cell <= config.LOW_CELL_VOLTAGE
    return state.voltage <= config.LOW_PACK_VOLTAGE


def _create_throttle_filter() -> ScalarKalmanFilter | None:
    if config.THROTTLE_FILTER_MODE != "KALMAN":
        return None
    return ScalarKalmanFilter(
        process_noise=config.THROTTLE_KALMAN_PROCESS_NOISE,
        measurement_noise=config.THROTTLE_KALMAN_MEASUREMENT_NOISE,
    )


def _connect_pigpio(retries: int = 5, delay: float = 1.0) -> pigpio.pi:
    """Try to connect to pigpiod, retrying on failure."""
    for attempt in range(1, retries + 1):
        pi = pigpio.pi()
        if pi.connected:
            return pi
        pi.stop()
        if attempt < retries:
            LOGGER.warning("pigpio attempt %d/%d failed, retrying in %.1fs", attempt, retries, delay)
            time.sleep(delay)
    LOGGER.warning("pigpio: all %d attempts failed", retries)
    return pigpio.pi()


def _create_bms() -> DalyBMS:
    if config.BMS_TRANSPORT == "BLE":
        return DalyBMSBle(
            config.BMS_BLE_ADDRESS,
            config.BMS_BLE_SERVICE_UUID,
            config.BMS_BLE_WRITE_UUID,
            config.BMS_BLE_NOTIFY_UUID,
            config.BMS_BLE_TIMEOUT_S,
        )
    return DalyBMS(config.BMS_PORT, config.BMS_BAUD)


def _create_motor_pair(pi: pigpio.pi) -> tuple[object, object]:
    if config.MOTOR_DRIVER_TYPE == "BTS7960":
        left_motor = BTS7960MotorDriver(
            pi,
            config.LEFT_MOTOR_RPWM,
            config.LEFT_MOTOR_LPWM,
            config.LEFT_MOTOR_REN,
            config.LEFT_MOTOR_LEN,
            inverted=bool(config.MOTOR1_INVERTED),
        )
        right_motor = BTS7960MotorDriver(
            pi,
            config.RIGHT_MOTOR_RPWM,
            config.RIGHT_MOTOR_LPWM,
            config.RIGHT_MOTOR_REN,
            config.RIGHT_MOTOR_LEN,
            inverted=bool(config.MOTOR2_INVERTED),
        )
        return left_motor, right_motor

    left_motor = MotorDriver(
        pi,
        config.MOTOR1_PWM,
        config.MOTOR1_DIR,
        inverted=bool(config.MOTOR1_INVERTED),
    )
    right_motor = MotorDriver(
        pi,
        config.MOTOR2_PWM,
        config.MOTOR2_DIR,
        inverted=bool(config.MOTOR2_INVERTED),
    )
    return left_motor, right_motor


def _send_system_telemetry(
    telemetry: CRSFTelemetry,
    stats: SystemStats,
    left_current_a: float = 0.0,
    right_current_a: float = 0.0,
) -> None:
    metrics = build_biba_system_metrics(
        cpu_pct=stats.cpu_percent(),
        mem_pct=stats.memory_percent(),
        left_motor_current_a=max(0.0, left_current_a),
        right_motor_current_a=max(0.0, right_current_a),
    )
    telemetry.send_system_stats(metrics=metrics)


def _battery_telemetry_current_a(current_a: float) -> float:
    return abs(current_a)


def _battery_telemetry_direction_code(current_a: float) -> int:
    if current_a > 0.0:
        return 1
    if current_a < 0.0:
        return 2
    return 0


def _battery_telemetry_direction_label(current_a: float) -> str:
    direction_code = _battery_telemetry_direction_code(current_a)
    if direction_code == 1:
        return "CHG"
    if direction_code == 2:
        return "DIS"
    return "IDLE"


def _apply_motor_trim(left_duty: float, right_duty: float, trim: float) -> tuple[float, float]:
    clamped_trim = _clamp_motor_trim(trim)
    if clamped_trim > 0.0:
        return left_duty, right_duty * (1.0 - clamped_trim)
    if clamped_trim < 0.0:
        return left_duty * (1.0 - abs(clamped_trim)), right_duty
    return left_duty, right_duty
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

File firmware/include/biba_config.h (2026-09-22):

#ifndef BIBA_CONFIG_H
#define BIBA_CONFIG_H

/* Global firmware configuration.
 *
 * Layering:
 *   1. The selected target may override any of the values below by
 *      defining them in targets/<TARGET>/target_config.h. That header
 *      is pulled in first here, and every default below is guarded by
 *      an `#ifndef`, so a target override always wins.
 *   2. Values here are the sensible fallbacks that are either
 *      non-board-specific (control loop rate, CRSF baud, protocol
 *      timeouts) or reasonable for a stock Blue Pill rig.
 *
 * Defaults intentionally mirror biba-controller/config.py and
 * docs/wiring.md so that standalone-mode behaviour on the STM32 lines
 * up with the Raspberry Pi runtime out of the box.
 */

#ifndef BIBA_NATIVE_TEST
#include "target_config.h"

#else /* BIBA_NATIVE_TEST — no target_config.h available */

/* Provide minimal defaults so portable modules compile under pio test -e native_test. */
#ifndef BIBA_SYS_CLOCK_HZ
#  define BIBA_SYS_CLOCK_HZ 125000000u
#endif
#ifndef BIBA_PWM_FREQUENCY_HZ
#  define BIBA_PWM_FREQUENCY_HZ 20000
#endif

#endif /* BIBA_NATIVE_TEST */

/* ========================================================================
 * CRITICAL SAFETY — NO FEATURE TOGGLES
 * These are always present and cannot be disabled (per D-05).
 * ======================================================================== */

/* --- Control loop timing ------------------------------------------------ */

#ifndef BIBA_CONTROL_LOOP_HZ
#  define BIBA_CONTROL_LOOP_HZ         500
#endif
#ifndef BIBA_TELEMETRY_PUBLISH_HZ
#  define BIBA_TELEMETRY_PUBLISH_HZ    200
#endif

/* --- Motor / PWM -------------------------------------------------------- */

#ifndef BIBA_PWM_FREQUENCY_HZ
#  define BIBA_PWM_FREQUENCY_HZ        20000   /* 20 kHz carrier, above audible */
#endif
#ifndef BIBA_PWM_DEADTIME_NS
#  define BIBA_PWM_DEADTIME_NS         500     /* dead-time between RPWM/LPWM */
#endif
#ifndef BIBA_BTS7960_RESET_PULSE_US
#  define BIBA_BTS7960_RESET_PULSE_US  100u
#endif
/* Standalone mode, open loop: on disarm/failsafe the outputs are zeroed
 * and, once both are at zero, the bridges are put to sleep (R_EN/L_EN low)
 * so the wheels coast instead of short-braking through the low-side
 * switches (which burned U2 —
 * kicad/variants/brushed-bts7960/analysis/M1-driver-failure.md).
 * While armed, zero duty keeps the bridges on: both low-side switches
 * short the motor and hold the wheels.  0 = bridges stay on when disarmed. */
#ifndef BIBA_MOTOR_COAST_WHEN_DISARMED
#  define BIBA_MOTOR_COAST_WHEN_DISARMED  1
#endif

/* --- Current sense calibration (BTS7960 IS pin, volts → amps) ---------- */

#ifndef BIBA_IS_ZERO_OFFSET_V
#  define BIBA_IS_ZERO_OFFSET_V        0.0f
#endif
#ifndef BIBA_IS_AMPS_PER_VOLT
#  define BIBA_IS_AMPS_PER_VOLT        1.0f
#endif

/* --- Battery / ADC ------------------------------------------------------ */

#ifndef BIBA_VBAT_DIVIDER_RATIO
#  define BIBA_VBAT_DIVIDER_RATIO      10.12f  /* calibrated 2026-05-26: APM module, 23.3V bat → 2858 raw */
#endif

/* 3DR Power Module battery current calibration defaults.
 * Targets with a real power module should override in target_config.h. */
#ifndef BIBA_IBAT_AMPS_PER_VOLT
#  define BIBA_IBAT_AMPS_PER_VOLT      1.0f
#endif
#ifndef BIBA_IBAT_ZERO_OFFSET_V
#  define BIBA_IBAT_ZERO_OFFSET_V      0.0f
#endif
/* PA5 rail tap uses its own divider. Defaults to the VBAT ratio because
 * the reference Blue Pill wiring shares the 1:11 ladder; a custom board
 * with a dedicated 12 V rail divider should override this in its
 * targets/<TARGET>/target_config.h. */
#ifndef BIBA_RAIL_12V_DIVIDER_RATIO
#  define BIBA_RAIL_12V_DIVIDER_RATIO  BIBA_VBAT_DIVIDER_RATIO
#endif
#ifndef BIBA_ADC_VREF_V
#  define BIBA_ADC_VREF_V              3.3f
#endif
#ifndef BIBA_ADC_MAX_COUNTS
#  define BIBA_ADC_MAX_COUNTS          4095    /* 12-bit ADC1 */
#endif

/* --- System clock ------------------------------------------------------- */

#ifndef BIBA_SYS_CLOCK_HZ
#  define BIBA_SYS_CLOCK_HZ            72000000u
#endif

/* --- CRSF link ---------------------------------------------------------- */

#ifndef BIBA_CRSF_BAUD
#  define BIBA_CRSF_BAUD               420000
#endif
#ifndef BIBA_CRSF_TIMEOUT_MS
#  define BIBA_CRSF_TIMEOUT_MS         500
#endif

/* --- SPI link ----------------------------------------------------------- */

#ifndef BIBA_SPI_LINK_TIMEOUT_MS
#  define BIBA_SPI_LINK_TIMEOUT_MS     200
#endif

/* --- RC channel assignments (0-based index, match biba-controller/config.py) */
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

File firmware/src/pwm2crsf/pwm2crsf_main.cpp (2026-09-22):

/* PWM → CRSF bridge — RP2040 entry point (env: rp2040_bridge_pwm2crsf).
 *
 * Measures servo-PWM high times on PWM2CRSF_INPUT_PINS with GPIO edge
 * interrupts and streams CRSF RC-channel frames out of UART0 at
 * PWM2CRSF_RC_PERIOD_MS. When any mapped input goes quiet the bridge
 * stops transmitting, which is exactly what BiBa sees when an ELRS
 * receiver loses its link, so BiBa's existing failsafe takes over.
 *
 * All the decision logic lives in pwm2crsf.c (native-tested); this file
 * only owns pins, timers and the UART. */

#include <Arduino.h>

#include "target.h"
#include "target_config.h"

extern "C" {
#include "pwm2crsf.h"
}

static const uint8_t kInputPins[PWM2CRSF_INPUT_COUNT] = PWM2CRSF_INPUT_PINS;

static const pwm2crsf_config_t kConfig = {
    .input_count      = PWM2CRSF_INPUT_COUNT,
    .min_us           = PWM2CRSF_MIN_US,
    .max_us           = PWM2CRSF_MAX_US,
    .valid_min_us     = PWM2CRSF_VALID_MIN_US,
    .valid_max_us     = PWM2CRSF_VALID_MAX_US,
    .input_timeout_us = PWM2CRSF_INPUT_TIMEOUT_MS * 1000u,
    .required_mask    = PWM2CRSF_REQUIRED_MASK,
    .map              = PWM2CRSF_CHANNEL_MAP,
    .idle             = PWM2CRSF_IDLE_VALUES,
    .invert_mask      = PWM2CRSF_INPUT_INVERT_MASK,
    .center_deadband_mask = PWM2CRSF_CENTER_DEADBAND_MASK,
    .center_deadband_us   = PWM2CRSF_CENTER_DEADBAND_US,
    .button_high_us   = PWM2CRSF_BUTTON_HIGH_US,
    .button_low_us    = PWM2CRSF_BUTTON_LOW_US,
    .button_min_interval_us = PWM2CRSF_BUTTON_MIN_INTERVAL_MS * 1000u,
    .buttons = {
        { PWM2CRSF_SPEED_BUTTON_INPUT, PWM2CRSF_SPEED_CRSF_CH,
          PWM2CRSF_SPEED_STEPS, PWM2CRSF_SPEED_BUTTON_LATCHING != 0 },
        { PWM2CRSF_DRIVE_BUTTON_INPUT, PWM2CRSF_DRIVE_CRSF_CH,
          2, PWM2CRSF_DRIVE_BUTTON_LATCHING != 0 },
        { PWM2CRSF_UNMAPPED, 0, 0, false },
        { PWM2CRSF_UNMAPPED, 0, 0, false },
    },
    .arm_input        = PWM2CRSF_ARM_INPUT,
    .arm_crsf_ch      = PWM2CRSF_ARM_CRSF_CH,
};

enum { kSlotSpeed = 0, kSlotDrive = 1 };

/* --- Pulse capture (ISR side) ------------------------------------------ */

static uint64_t          s_rise_us[PWM2CRSF_INPUT_COUNT];
static volatile uint32_t s_width_us[PWM2CRSF_INPUT_COUNT];
static volatile uint32_t s_pulse_seq[PWM2CRSF_INPUT_COUNT];

static void on_gpio_edge(uint gpio, uint32_t events)
{
    uint64_t now = time_us_64();
    for (unsigned i = 0; i < PWM2CRSF_INPUT_COUNT; ++i) {
        if (kInputPins[i] != gpio) continue;

        bool rise = (events & GPIO_IRQ_EDGE_RISE) != 0;
        bool fall = (events & GPIO_IRQ_EDGE_FALL) != 0;
        if (rise && fall) {
            /* Both edges latched before we got here: the pulse width is
             * unknown. Resync on the current level. */
            rise = gpio_get(gpio);
            fall = false;
            s_rise_us[i] = 0;
        }
        if (rise) {
            s_rise_us[i] = now;
        } else if (fall && s_rise_us[i] != 0) {
            s_width_us[i] = (uint32_t)(now - s_rise_us[i]);
            s_pulse_seq[i]++;
            s_rise_us[i] = 0;
        }
        return;
    }
}

/* --- Main-loop state --------------------------------------------------- */
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

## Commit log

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2026-03-24 feat: R2-D2 sound system — buzzer melodies, SOS beacon, EdgeTX tones
    Robot (piezo buzzer via pigpio PWM):
    - New melodies.py with 9 signature patterns (startup Bi-Ba, arm, disarm,
    low voltage, failsafe, SOS morse, connected, disconnected, shutdown)
    - Buzzer rewritten with play()/play_async() melody player + thread safety
    - BeaconManager: auto-SOS after configurable failsafe delay (BEACON_DELAY_S)
    + manual toggle via RC channel (CH_BEACON=5)
    - Config: BEACON_ENABLED, BEACON_DELAY_S (300s default), CH_BEACON
    - main.py: startup/shutdown jingles, connection state sounds, beacon loop
    EdgeTX transmitter (Lua playTone):
    - Startup 'Bi-Baaa' jingle in init()
    - Connected/disconnected transition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
    [beacon.py, config.py, main.py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]
2026-03-25 feat: motor speed ramping (slew rate limiter) with direction protection
    Add SpeedRamp class that limits acceleration/deceleration rates and
    guarantees zero-crossing before direction reversal to protect gear
    motors (MY1016Z3 350W) from instant torque changes.
    - New motors/ramping.py: SpeedRamp with asymmetric accel/decel rates,
    deadband, and mandatory pass-through-zero on direction change
    - Integrate into DifferentialDrive: ramp applied per-motor after
    arcade mixing, drive() accepts dt parameter
    - Config: RAMP_ACCEL_RATE (2.0), RAMP_DECEL_RATE (3.0), MOTOR_DEADBAND (0.05)
    - Failsafe/disarm: smooth deceleration via ramp instead of instant stop
    - Program shutdown: emergency_stop() bypasses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
    [config.py, driver.py, main.py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]
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2026-03-25 fix: pigpiod startup race causes telemetry-only mode
    Root cause: pigpiod forks and parent exits, but daemon process dies before
    Python connects. Stale /var/run/pigpio.pid blocks restart.
    Two-level fix:
    - Dockerfile CMD: rm stale PID + sleep 1 after pigpiod fork
    - main.py: _connect_pigpio() retries pigpio.pi() up to 5 times with 1s delay
    Symptoms: motors don't spin, GPIO sendto() absent in strace, logs show
    'Can\'t lock /var/run/pigpio.pid' + 'telemetry-only mode'
    [main.py]
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2026-03-25 fix: use non-zero GPS coords for valid fix, fix GSpd unit conversion in Lua
    [telemetry.py]
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2026-03-25 fix: eliminate input latency by draining CRSF buffer and threading BMS
    Root cause: get_channels() processed ONE frame per call, causing stale
    frames to backlog with 20ms delay each. BMS polling blocked the main
    loop for up to 1.4s, during which frames piled up.
    Changes:
    - get_channels(): drain all pending frames non-blockingly, return latest
    - BMSPoller: new background-threaded BMS reader (bms/poller.py)
    - main.py: BMS now polled in daemon thread, main loop never blocks
    - Tests: 2 new CRSF drain tests + 5 BMSPoller tests, all 104 pass
    [main.py, poller.py, receiver.py]
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2026-03-26 feat: RC melody channel (CH8) + startup melody config
    - Add CH_MELODY and STARTUP_MELODY to config.py
    - Add melody zone selection in main loop (FUN_PLAYLIST via CH8)
    - Add play_named/play_named_async/play_blheli stubs to _NullBuzzer
    - Replace startup_tone() with play_named(STARTUP_MELODY)
    - Add env vars to docker-compose.yml
    [config.py, main.py]
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2026-03-26 feat: switch BTS7960 to hardware PWM
    - replace software PWM with pigpio hardware_PWM for BTS7960
    - move right LPWM to GPIO19 and restore separate LEN pins
    - update compose/env/docs to hardware-capable pin mapping
    - add regression tests for hardware PWM behavior
    [config.py, driver.py]
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2026-03-26 Replace neutral guard with zero-hold pause on reversal
    Remove _ThrottleDirectionGuard — it did not solve the BTS7960 bark on
    rapid direction change because the problem is physical: the motor is
    still spinning when reverse PWM is applied.
    Add RAMP_ZERO_HOLD_S (default 0.15s) to SpeedRamp. After the ramp
    decelerates to zero during a direction change, the output stays at zero
    for the configured duration, giving the motor time to physically stop
    before reverse current flows. This addresses the root cause documented
    in BTS7960 datasheets: rapid reverse under load causes high inrush
    current and audible bark.
    Config / docs / compose updated; guard env removed.
    [config.py, driver.py, main.py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]
2026-03-26 fix: pigpiod -s 1 for 20kHz PWM, dynamic range, RAMP_DECEL_RATE=1.0
    - Dockerfile: pigpiod -s 1 -t 0 (1µs sample rate → 20kHz with 50 duty levels)
    - driver.py: query get_PWM_real_range() and set_PWM_range() instead of hardcoded 255
    - RAMP_DECEL_RATE default 2.0→1.0 (100%→0% in 1 second)
    - Added PWM_FREQUENCY_HZ to docker-compose.yml
    - Updated docs, .env.example, tests
    [config.py, driver.py]
2026-03-26 fix: use hardware_PWM for BTS7960 (20kHz, 1M duty levels)
    - pigpiod -s 1 fails on Pi Zero 2W (mbox init), reverted to plain pigpiod
    - BTS7960MotorDriver now uses hardware_PWM() instead of software set_PWM_dutycycle
    - 20kHz frequency (inaudible) with 1,000,000 duty cycle steps (vs 25 with soft PWM)
    - Left motor pins 18(PWM0) + 13(PWM1) use separate HW channels, no conflict
    - RAMP_DECEL_RATE=1.0 from previous commit still in effect
    [driver.py]
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2026-03-26 feat: PWM speech playback through motor coils at startup
    Add WAV file playback via PCM-over-PWM duty cycle modulation.
    Motor coil inductance acts as natural low-pass filter to reconstruct
    audio from a 25kHz carrier with per-sample duty cycle updates.
    - buzzer/wav_player.py: load_wav() + play_samples() engine
    - MotorSynth: play_wav() / play_wav_async() with lock/interrupt support
    - Dockerfile: install espeak-ng, pre-generate 'Я ВЕРНУЛСЯ' WAV at build
    - config: STARTUP_VOICE / STARTUP_VOICE_ENABLED env vars
    - main.py: play voice before startup melody
    - 14 new tests for WAV loading, playback, and MotorSynth integration
    [config.py, main.py, motor_synth.py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]
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2026-03-26 fix: normalise WAV volume to full range, skip melody when voice plays
    [main.py, wav_player.py]
2026-03-26 fix: lower carrier to 4kHz + downsample WAV to 8kHz for louder playback
    25kHz carrier caused very high coil impedance (~314Ω for 2mH motor),
    severely limiting current variation. At 4kHz impedance drops to ~50Ω,
    allowing 6x more current = much louder audio.
    8kHz sample rate reduces Pi Zero CPU load (125µs/sample vs 45µs).
    [wav_player.py]
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2026-03-26 fix: skip samples to maintain real-time playback speed
    On Pi Zero with 4 PWM pins, each hardware_PWM call takes ~150µs over
    the pigpio socket. At 8kHz (125µs/sample), the loop can't keep up and
    plays 5x slower. Now tracks elapsed real time and skips ahead to the
    correct sample index, maintaining correct playback duration.
    [wav_player.py]
2026-03-26 fix: raise carrier to 16kHz (inaudible for most, lower impedance than 25kHz)
    [wav_player.py]
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2026-03-26 feat: add grouped voice phrases for robot events
    Map StarCraft phrases to runtime events and select clips by meaning.
    Grouped voice events now support round-robin or random selection,
    with round-robin as the default.
    Implemented groups for startup, arm, disarm, connected,
    disconnected, failsafe, low_voltage, and sos.
    Removed the old single startup/arm voice assets.
    [config.py, main.py, voice_selector.py]
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2026-03-30 Revert "fix: use enable pins for BTS7960 hardware PWM"
    This reverts commit 20478d8a0a24ca88cb380bab58db0f985f858c10.
    [driver.py]
2026-03-30 Revert "fix: switch BTS7960 defaults to hardware PWM wiring"
    This reverts commit 6bb448f5e804b4104f4902527d2564727451e784.
    [config.py]
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2026-04-01 fix: update melody for arm sequence to include G4 and remove D#4
    [melodies.py]
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2026-04-06 Add neutral assist activity logging and format metrics for assisted drive
    - Introduced logging for neutral assist activity to monitor when the system is armed but not actively driving.
    - Added helper functions to format assisted drive metrics for logging, including detailed information about drive mode, assist input/output, and IMU status.
    - Updated the main control loop to log neutral assist activity based on specific conditions.
    - Enhanced unit tests to cover new logging functionality and ensure correct behavior of the neutral assist activity checks.
    [main.py]
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2026-04-08 feat: localize motor test and PID tuning interfaces to Russian
    - Added Russian translations for field labels, error messages, and UI text in motor test and PID tuning pages.
    - Updated HTML templates and JavaScript to reflect the new language settings.
    - Modified error handling to provide localized messages for invalid inputs and operational states.
    - Enhanced test cases to validate the new Russian language outputs and error messages.
    [pid_tuning.py, settings_store.py]
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2026-04-22 review: honour target LED polarity, split 12V rail divider, fix wiring table pin
    Agent-Logs-Url: https://github.com/GOODWORKRINKZ/biba/sessions/2d0ff9c9-369d-4c87-9ac7-19a4101c7a4d
    [biba_config.h, target_config.h]
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2026-04-28 feat: add STM32F103 hardware support with system clock definition and error handling in HAL
    [biba_config.h]
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2026-05-09 feat(rp2040): add trim mode functionality with melodies for enter/exit and reverse backup beep
    [biba_config.h]
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2026-05-14 feat(01-03): add Unity test suite for biba_ramp — 8 tests GREEN; fix native_test build filter (main_rp2040.cpp, melody.c) and BIBA_NATIVE_TEST guard in biba_config.h
    [biba_config.h]
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2026-05-17 docs(thermal): integrate industry references into design spec — Rds_on formula, synchronous rectification, dead time, capacitor design
    - Add conduction loss formula: P_loss = I² × Rds_on
    - Compare BTN8982TA (9W @ 30A) vs BTS7960 (14.4W) — 35% reduction
    - Validate MOSFET choice for 24V via Arduino forum community consensus (<200V rule)
    - Document synchronous rectification (Cytron Design) replaces diode losses
    - Detail dead time protection (A3941 IC prevents shoot-through)
    - Explain main capacitor role in voltage stabilization and thermal performance
    - Add gate driver charge pump feature (A3941) for low-voltage reliability
    References:
    - Cytron Design: DC Motor Driver – How it works (R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
    [bts7960.c]
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2026-05-19 feat(05-wave2): route current sense through ADS1115; add Ibat to voltage_sense
    - firmware/src/drivers/current_sense.c:
    add #include ads1115.h
    replace biba_hal_adc_sample/volts with ads1115_read_channel_v()
    sample() now takes uint8_t ADS1115 channel args instead of ADC chan ints
    biba_current_sense_left/right() use BIBA_ADS1115_CHAN_IS_* defines
    - firmware/src/drivers/voltage_sense.h/.c:
    add biba_voltage_sense_ibat_a() reading BIBA_ADC_CHAN_IBAT
    guarded by #ifdef BIBA_ADC_CHAN_IBAT (returns 0.0 if not defined)
    - firmware/include/biba_config.h:
    add BIBA_IBAT_AMPS_PER_VOLT=1.0f default (guarded #ifndef)
    add BIBA_IBAT_ZERO_OFFSET_V=0.0f default (guarded #ifndef)
    - firmware/src/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
    [biba_config.h, current_sense.c]
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2026-05-19 fix(05): VBAT_DIVIDER_RATIO 5.7→10.1 for 6S (GM v1.0 PM clone), clamp 65→30 V
    [target_config.h]
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2026-05-22 fix(rp2040): disable per-motor current limiter until Phase 06 IS HW is wired
    [target_config.h]
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2026-05-22 Enhance IS-PoC analysis and visualization tools
    - Updated frequency analysis functions to improve accuracy in the RPM band (1-200 Hz).
    - Added time-domain plotting script to visualize raw ADC samples against time.
    - Introduced new PNG artifacts for time-domain plots and spectrum analysis.
    - Adjusted unit tests to reflect changes in frequency estimation and noise characteristics.
    - Improved handling of DC offsets in frequency estimation algorithms.
    [duty_025_FWD_sps10000.csv, duty_025_REV_sps10000.csv, duty_050_FWD_sps10000.csv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]
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2026-05-22 feat(06): retune analyser to 50-1500 Hz band; PI defaults from open-loop measurement
    After the ADC clock fix the real IS-modulation fundamental is in the
    hundreds of Hz, not 2-25 Hz. Reanalysed the fresh duty sweep:
    duty FWD-ZC REV-ZC
    25% 192 Hz 159 Hz
    50% 435 Hz 769 Hz (REV outlier)
    75% 667 Hz 667 Hz
    100% 909 Hz 909 Hz
    R² FWD = 1.000 across FFT/ZC/AC. Open-loop gain ≈ 9.6 Hz per % duty
    (≈ 950 Hz per unit duty) with a ~50 Hz dead-zone intercept.
    - is_poc_analyse.py: FFT mask 1..200 → 50..1500 Hz; AC lag floor 5 ms
    → 0.67 ms, cap 500 ms → 50 ms; PSD x-axis 0..1500 Hz.
    - is_poc_pid.py: Kp 0.01 → 0.001 (≈1 % duty p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
    [duty_025_FWD_sps10000.csv, duty_025_REV_sps10000.csv, duty_050_FWD_sps10000.csv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]
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2026-05-22 Add IS signal PoC scripts for RPM and step response testing
    - Introduced `is_poc_pid.py` for open-loop RPM control with enhanced PID parameters and error handling.
    - Added `is_poc_step.py` for open-loop step response testing, capturing frequency response and plotting results.
    - Created CSV output files for both RPM and step tests to log measurements.
    - Generated PNG plots for visualizing RPM and step response data.
    - Updated argument parsing to include new parameters for stiction and feed-forward control in PID testing.
    [rpmrun.csv, step.csv]
2026-05-22 fix: update stiction floor default to 20% and adjust scaling for PID gains
    [rpmrun.csv]
2026-05-23 feat(06): sub-window ZC detector + diagnostic toolchain
    Algorithm change (firmware):
    - Replace global-mean Schmitt with 8-block sub-window Schmitt (A2).
    Bench: TRAP mean-error 92->46 Hz, SIN mean-error 164->44 Hz.
    - Proportional transient blanking: delta-duty>3pp->25ms, >8pp->50ms.
    - Detector returns 0 under hand-stall (was: 1000 Hz from PWM ripple)
    so controller no longer reduces duty under load.
    - Add SWEEPRAW firmware command: captures N x 1024-sample raw windows
    during one sin/trap cycle for offline algorithm analysis.
    Diagnostic tools (scripts/):
    - is_poc_sweep.py: artifact names parametrized (shape/amp/period/ts).
    - is_poc_sweepraw.py: SWEEPRAW host driver, delegates to analyzer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
    [bench.csv, rpmrun.csv, rpmrun1.csv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]
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2026-05-25 Add drive capture test data and improve debug session handling
    - Introduced a new CSV file `thr_step_test.csv` containing test data for drive capture, including baseline idle, sharp step changes, and coast observations.
    - Enhanced the `enable_debug` method in `is_biba_drive_capture.py` to reset the state from previous sessions before enabling debug mode, ensuring a clean start for each session.
    [thr_step_20260525_095008.csv, thr_step_test.csv]
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2026-05-25 feat(08-01): LittleFS blackbox structs, C++ wrapper, CDC write HAL, Unity tests
    - blackbox.h: biba_blackbox_header_t (32 B) + biba_blackbox_record_t (31 B),
    static-assert guards, full extern-C API surface
    - blackbox.cpp: LittleFS init/format/open/write/close/list/send/delete;
    sscanf+snprintf filename validation prevents path traversal (T-08-01)
    - biba_hal_serial: add write_bytes + write_str for binary CDC streaming
    - biba_config.h: BIBA_BLACKBOX_RATE_HZ/FIELD_MASK/MIN_FREE_KB/CH_BLACKBOX
    - platformio.ini: 4 MB LittleFS partition; exclude motor_bridge.c + blackbox.cpp
    from common native filter; fix phase-7 motor_bridge native link regression
    - test_blackbox: 4/4 Unity tests pass (header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
    [biba_config.h]
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2026-05-26 feat(phase-11): IS-pin DC load gate + VBAT/IBAT capture + battery sag research
    Plans 11-01 through 11-05 — 5/5 complete.
    Wave 1 (11-01): Python load-gate grid search validates THRESH=1.5, QMAX=10.0
    Wave 2 (11-02): Battery sag Pearson-r=0.890 (controlled capture recommended)
    Wave 2 (11-03): VBAT/IBAT in SWEEPRAW_BOTH firmware + Python parser
    Wave 2 (11-04): Throttle vs load disambiguation ADR (d_freq/d_DC gradients)
    Wave 3 (11-05): Firmware load gate — HIGH_LOAD=7 enum, mean_adc field,
    biba_rpm_spectral_apply_load_gate(), 4 new tests
    Firmware: 88 tests, 0 failures. pio run SUCCESS.
    Phase 11 complete (88/88 tests, 0 failures).
    [biba_config.h]
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2026-05-27 feat(phase-12-plan-01): reorganize biba_config.h with 17 feature toggles
    Introduce BIBA_FEATURE_<NAME> compile-time toggle system:
    - 17 feature toggles across RPM chain (7), Safety (2), Comfort (4), Drive (3)
    - BIBA_FEATURE_RPM_CLOSED_LOOP master switch replaces BIBA_OPEN_LOOP
    - Each feature section groups toggle + all parameters together
    - Dependency #error checks at bottom: PI→DR, DUAL_WINDOW→SPECTRAL,
    LOAD_GATE→SPECTRAL, ANTI_STALL→SPECTRAL
    - Backward compat: #ifdef BIBA_OPEN_LOOP → RPM_CLOSED_LOOP=0 with #warning
    - BIBA_REVERSE_PIP_ENABLED → BIBA_FEATURE_REVERSE_PIP (with compat shim)
    Module headers (zc_detector, rpm_spectral_estimator, rpm_pi):
    - All #define constants wra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
    [biba_config.h, target_config.h]
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2026-07-20 feat(firmware): RPICO_RP2040_BLDC PoC — MCP2515 + ODrive CAN driver, builds under pico
    Создаёт минимально работающий прототип firmware для новой платы
    RPICO_RP2040_BLDC: инициализация SPI0 на RP2040, драйвер MCP2515
    (reset, настройка битрейта 250 кбит/с, режим Normal, фильтры
    CANSimple), отправка/приём CAN-кадров через ring-очередь, а также
    протокольный драйвер ODrive CANSimple (Set_Input_Vel, Set_Limits,
    Get_*, Heartbeat-декодер, периодический 50 Гц tick).
    Добавлен новый target RPICO_RP2040_BLDC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
    [ads1115.c, aht30.c, main_rp2040.cpp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]
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2026-08-14 firmware: RP2040 BLDC + ODrive bring-up fixes
    MCP2515 CAN driver:
    - fix SPI READ/BIT-MODIFY to single full-duplex transactions
    - fix acceptance-filter mask (0x01F cmd_id) and SIDH shift
    - fix bit timing CNF2 0xD0->0xA0 (was ~222 kbit, 12% off 250 kbit)
    - fix OPMOD detection mask in reset_and_wait
    ODrive CANSimple driver:
    - decode heartbeat axis_state from byte 4
    - Set_Axis_State sends IDLE=1 / CLOSED_LOOP=8 (0 is ignored by ODrive)
    - fix Set_Limits payload order (vel_limit then current_limit)
    - re-issue Set_Limits on every arm/disarm edge
    - retry CLOSED_LOOP while armed until heartbeat confirms state 8
    Mode standalone:
    - arm edge enables ODrive instead of thermal reset
    - BLDC 10 Hz time-ba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
    [odrive_wheel_motor_geared_config.json]
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2026-09-11 feat(odrive): add UART transport and recover from CAN bus wedges
    - Introduce transport-agnostic drivers/odrive.h API with CAN and UART
    backends (odrive_can.c / odrive_uart.c) selected by
    BIBA_ODRIVE_LINK_UART
    - Add UART ASCII backend with liveness polling and telemetry reads
    - Auto-recover MCP2515 from bus-off (EFLG TXEP/TXBO) by full chip reset
    - Watchdog-known-silent ODrive nodes via CAN reset command
    - Surface telemetry (voltage, current) and new debug counters
    - Add CRSF telemetry uplink (battery + GPS frames) in standalone mode
    - Add RPICO_RP2040_BLDC UART build envs (standalone/companion/combined)
    - Raise BLDC target limits to 15 rev/s and document gear ratio
    [mcp2515.c, odrive_can.c, odrive_uart.c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]
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2026-09-11 firmware(odrive): add error-clear, stiction torque FF, lower vel limits
    - Add biba_odrive_clear_errors() over CAN (Clear_Errors 0x018) and
    UART (ASCII `sc`), called on arm/disarm to clear latched ODrive errors.
    - UART drive loop now sends Set_Input_Vel with a stiction feed-forward
    torque kick in the direction of motion (zero at standstill) to break
    static friction without integrator wind-up.
    - Tune RPICO_RP2040_BLDC: max vel 15->10 rev/s, torque FF 0->0.2 Nm.
    - Add odrive_pid_step / step_response / step_analyze scripts and
    step-response CSV artifacts.
    [baseline_g002.csv, g004.csv, step.csv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]
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2026-09-16 feat(firmware): drop STM32F103 targets, restrict CI to native tests
    The project is RP2040-only now. Remove the STM32 target
    directories, the single-timer motor-PWM HAL, the semihosting
    debug harness and the 8 KB-RAM clone linker script, and strip
    the corresponding PlatformIO envs, ldscripts and docs.
    Report the change explicitly in firmware/README.md,
    targets/README.md, docs/onboarding.md and docs/variants.md.
    Replace the STM32F103 build-and-upload matrix in G-Build-All.yml
    with a call to a new G-Build-Firmware-Native-Tests.yml workflow
    that only runs `pio test -e native_test`; per-target builds are
    local, so drop the STM32F103 workflow and its firmware artefacts.
    Also add the BIBA2/SBIBA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
    [BULKHEAD_L.dxf, BULKHEAD_R.dxf, COVER_TOP.dxf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]
2026-09-16 refactor: modernize typing, hoist ClassVar annotations, and silence intentional broad excepts
    Replace Optional[X] with X | None, move Callable/Sequence/Mapping
    imports to collections.abc, annotate mutable class-level dicts as
    ClassVar, use Self for __enter__, simplify int(round(...)) to round(),
    and add targeted noqa: BLE001 comments to intentional catch-all
    handlers so the polling/telemetry loops survive driver errors. Also
    tidy import ordering and wrap long import lists across the controller
    and tests.
    [client.py, current_sense.py, daly.py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]
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2026-09-16 feat(firmware): add PWM2CRSF_RP2040 target bridging HotRC PWM to CRSF
    Introduce a standalone Pico target that converts 6 servo-PWM channels
    from a HotRC receiver into CRSF on UART0, letting the bridge replace an
    ELRS receiver on BiBa's CRSF port without firmware changes. Add the
    portable pwm2crsf logic (channel mapping, inversion, glitch filter, and
    cycle button for the 3-position speed switch), the RP2040 entry point,
    target headers, docs, and a dedicated platformio env. Extend crsf.c with
    the encoder side (pack_channels, pack_link_stats, build_frame) and add
    native tests for both modules.
    [pwm2crsf.c, pwm2crsf_main.cpp, target_config.h]
2026-09-16 feat(firmware): generalize cycle button into multiple step buttons with arm interlock
    Replace the single cycle button with an array of up to four step buttons,
    each with its own input, CRSF channel, step count and latching mode, so
    both the speed mode (PWM4 → CH6) and the drive mode (PWM5 → CH10) can be
    driven from the HotRC transmitter.
    Add an ARM interlock that forces the arm channel to CRSF_MIN after boot
    and after every link loss until the arm input has been seen low, plus a
    required_mask so only essential inputs (wheel, trigger, ARM) gate the
    link while a dead auxiliary button merely drops its channel to the idle
    value. Rename pwm2crsf_reset_cycle to pwm2crsf_reset_on_link_loss and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
    [pwm2crsf.c, pwm2crsf_main.cpp, target_config.h]
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2026-09-17 feat(kicad): generate KiCad schematic for brushed-bts7960 from EasyEDA netlist
    - scripts/gen_schematic.py: netlist.json -> .kicad_sch + custom symbols
    - kicad/common/symbols/biba.kicad_sym: RP2040, BTN7970, SN74AHC244, BMI160, SPX3819, SKMW30G
    - brushed-bts7960.kicad_sch: 57 components, 56 nets, ERC 0 errors 0 warnings
    - scripts/easyeda_netlist.py: also emit netlist.json
    [brushed-bts7960.kicad_sch]
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2026-09-17 fix(kicad): regenerate variant with stable UUIDs and correct text justification
    - switch to deterministic UUIDv5 so regeneration yields minimal diffs
    - map flipped text anchors to right justify and align sheet UUIDs across files
    [brushed-bts7960.kicad_sch]
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2026-09-18 fix(firmware): coast when disarmed and soft open-loop ramp for BTS7960
    - mode_standalone.c: sleep bridges (R_EN/L_EN low) once disarmed/failsafe and at rest, so wheels coast instead of short-braking through the low-side switch that burned U2; wake bridges for melody playback
    - ramp.c/h: zero-hold keyed to last non-zero direction so a reversal through a centred stick also waits the pause; cap zero_time_s to avoid float overflow; remove accidental terminal paste
    - biba_hal_motor_rp2040.c: fix audio silence on inverted LPWM (level above wrap) and park LPWM low across mode switches so no reverse pulse escapes
    - target_config.h: open-loop ramp 2.0/1.0/0.5 accel-decel-reverse + 400 ms zero hold (s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
    [biba_config.h, target_config.h]
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
